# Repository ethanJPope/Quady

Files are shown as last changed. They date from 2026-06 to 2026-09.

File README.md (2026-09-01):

# Quady

Quady is my 8-servo 3D-printed quadruped robot dog project. The goal is to build a real walking robot from scratch, then eventually connect the physical design to simulation and AI training with NVIDIA Isaac Sim / Isaac Lab. This project mixes the parts of engineering I enjoy most: CAD, 3D printing, electronics, programming, and robotics. It is still a work in progress, but the main goal is to get a first version walking and learn enough from it to make the next version better.

## Project Goals

- Build a compact 8-servo quadruped robot dog.
- Design and print the body and legs myself.
- Control the servos through serial bus servo hardware.
- Develop basic movement tests before trying more advanced walking.
- Use simulation and AI training later once the physical design is far enough along.
- Document the process honestly, including the mistakes and redesigns.

## Current Design

Quady is currently an 8-servo robot dog, which means each leg has two powered joints. This keeps the first version simpler than a 12-servo design while still being complex enough to learn real quadruped mechanics and control.

PXL_20260830_213550859 MP

The current plan is:

- 4 legs
- 2 servos per leg
- 8 total servos
- 3D-printed frame and leg parts
- Serial bus servo control
- Future simulation/training work in Isaac Sim and Isaac Lab

## Hardware

Known hardware for the current version:

| Part | Notes |
|---|---|
| Feetech STS3215 servos | 12V serial bus servos |
| Waveshare Bus Servo Adapter | Used to interface with the servos |
| 3D-printed frame and legs | Designed and iterated through CAD |
| External power | Needed for reliable servo testing |

This section will get more specific as the electronics and final mechanical layout become locked in.

In depth assembly instructions can be found here. [ASSEMBLY.md](ASSEMBLY.md).

## Software

The software side is being built in stages:

1. Basic servo communication.
2. Individual joint testing.
3. Leg movement tests.
4. Full-body pose control.
5. Simple walking patterns.
6. Simulation and AI training experiments.

The early focus is on making the real robot move reliably before making the software too complicated.

## Roadmap

- [ ] Finish first complete CAD version.
- [ ] Print and assemble the first full robot body.
- [ ] Test each servo and joint individually.
- [ ] Create basic standing poses.
- [ ] Add simple movement patterns.
- [ ] Record a first walking demo.
- [ ] Start Isaac Sim / Isaac Lab setup.
- [ ] Experiment with AI training once the mechanical design is usable.

## Why I Am Building This

I wanted a project that combines hardware and programming in a way that actually feels challenging. A robot dog is a good target because it forces me to deal with mechanical design, electronics, control systems, and eventually simulation.

This is also a project I want to be able to show as real engineering work, not just a quick demo. The first version does not need to be perfect, but it needs to teach me enough to keep improving it.

## Status

Quady is under active development. The design has changed from a 12-servo robot dog to an 8-servo robot dog to make the first version more realistic and easier to finish.

More build notes, photos, CAD exports, wiring details, and control code will be added as the project develops.

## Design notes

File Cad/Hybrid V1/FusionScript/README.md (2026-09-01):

# Quady Hybrid V1 Fusion script

`QuadyHybridSkeleton.py` creates a new Fusion 360 design for the first hybrid
base-layout check. It does not open or modify the existing Quady V1/V2 CAD.

## What it creates

- Two 260 x 190 mm structural board bodies.
- A 50 mm plane-to-plane board layout offset (46.8 mm clear space between
  3.2 mm board solids).
- Four leg-pivot markers at the current 150 x 100 mm spacing.
- Two 139 x 47 x 40 mm battery keepouts.
- Two Waveshare adapter keepout zones.
- A 75 x 40 mm ESP32-S3 DevKitC-style placeholder envelope around the
  62.74 x 25.40 mm board footprint.
- An optional Raspberry Pi 3B zone.
- An adjustable Arducam camera zone.
- Named millimeter user parameters in Fusion. These drive the initial
  generation; post-run edits are not yet fully associative.

## Run it in Fusion 360

1. Open Fusion 360.
2. Open **Utilities > Add-Ins > Scripts and Add-Ins**.
3. Choose the **Scripts** tab.
4. Click the **+** button and choose **Script or add-in from device**.
5. Select this folder:

   `D:\Quady\Cad\Hybrid V1\FusionScript`

6. Select `QuadyHybridSkeleton.py` and click **Run**.
7. Confirm the new document contains the four named Browser components and
   visible board, battery, electronics, and pivot-marker geometry.

The output is a layout skeleton. Do not use it as a manufacturing file yet. We
will next add the real leg-cassette mounting interface and inspect the physical
clearances. Fusion's Personal plan may show a document-limit read-only banner;
the script remains the reproducible source until the generated document can be
saved.

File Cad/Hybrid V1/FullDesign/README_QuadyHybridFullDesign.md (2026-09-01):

# Quady Hybrid V2 full design

Generated by `QuadyHybridFullDesign.py`.

## Fusion Browser map

| Section | What it contains | Physical treatment |
|---|---|---|
| `10_NONPRINTED_STRUCTURE_FR4_TWO_LAYER` | two 260 x 190 x 3.2 mm boards and four 50 mm spacers | buy/cut: 1.6 mm FR-4 per layer; 6061 aluminum spacers |
| `20_PRINTED_INTERCHANGEABLE_LEG_PARTS` | four leg modules, each with a hip cassette, upper link, and knee cradle | print: PETG-CF or PA12 nylon |
| `30_NONPRINTED_STS3215_SERVOS_12V` | eight positioned servo envelope proxies at the hip/knee shaft datums | buy: STS-3215 12 V servos |
| `40_NONPRINTED_POWER_CONTROL_CAMERA` | two exact battery envelopes, two adapter boards, ESP32-S3, small LiPo, optional Pi 3B, camera, and camera base plate | buy: LiPo/PCBs/camera; print only the retainers/base plate |
| `50_NONPRINTED_FASTENERS_AND_MOUNTING` | M4 cassette/perimeter bolt proxies | buy: stainless M4/M3 hardware |
| `60_REFERENCE_PRESERVED_LOWER_LEG_AND_FOOT` | hidden envelope references for the existing foot/lower leg | keep the existing physical part; do not print these boxes |
| `70_REFERENCE_GROUND_AND_DATUMS` | ground plane and contact datums | construction/reference geometry |
| `80_REFERENCE_STS3215_STEP_SOURCE` | the supplied `D:\Quady\ST3215.step` imported at source origin | reference only until shaft alignment is checked |

## Confirmed design inputs

- Four hip centers use the existing 150 x 100 mm spacing.
- Eight STS-3215 12 V servos are represented: hip and knee on each leg.
- Two batteries are each 139 x 47 x 40 mm.
- Each battery has its own four-servo Waveshare adapter reservation.
- The preferred controller is the supplied ESP32-S3 board; the Pi 3B is only an underside reservation.
- The ground datum is intentionally below the preserved foot envelope, with the target pose encoded from the current 53.882 mm X/Z hip-to-knee vector.

## Print guidance

- Use PETG-CF or PA12 nylon for the structural printed parts.
- Use at least four perimeter walls and 35-45% gyroid infill.
- Print the flat cassette plate and upper link in their shown flat orientations where practical.
- Keep at least 5 mm of solid material around cassette holes; use washers under the board.
- Do not use the battery or servo proxy bodies as print geometry.

## Required measurement gate before final manufacturing CAD

The model is mechanically organized and validated, but these interfaces remain explicitly provisional:

1. STS-3215 outer envelope, shaft center, and mounting-ear pattern.
2. Waveshare adapter outline, hole pattern, connector keepouts, and wire exits.
3. OVO Arducam camera outline and bracket/bolt pattern.
4. Existing foot/lower-leg connection and its real pivot hardware.
5. Actual board material thickness if a different stock thickness is purchased.

Replace the relevant master values in the generator, rerun it, then print one hip cassette and one knee cradle as fit-checks before printing all four legs.

The generated validation record is in `QuadyHybridFullDesign_manifest.json`.

## Alignment feedback loop

The `65_REFERENCE_ALIGNMENT_AUDIT` section is intentionally visible. Use it
as a review gate after every geometry change:

1. Fit the whole assembly in isometric view and confirm all four printed upper links and all eight servo proxies are present.
2. Switch to top view and confirm the four hip axes form the 150 x 100 mm rectangle and each cassette is centered on its axis.
3. Switch to front view and confirm each hip axis, servo shaft, upper-link boss, knee axis, and knee servo shaft are coaxial.
4. Switch to side view and confirm each thin hip-to-knee centerline terminates on both axis datums.
5. Confirm each visible preserved-foot envelope begins at its knee axis; hide the audit group only after this visual check.
6. If any view fails, change the master transform/pose, rerun the generator, and repeat the checks before printing.

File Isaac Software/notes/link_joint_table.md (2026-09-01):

# Quady Link And Joint Table

This file is the planning map for turning Quady from CAD into a robot articulation for URDF, USD, Isaac Sim, and Isaac Lab.

Rule: one link name should represent one rigid physical thing that moves as a single piece.

Current Quady design note: Ethan is using 2 servos per leg, 8 servos total. Earlier 12-DOF assumptions should not be used unless the CAD changes again.

Current CAD organization note: the Fusion assembly is not organized with CAD joints yet. The URDF joint axes are being inferred from the physical servo shaft directions and visual CAD screenshots.

## Link Inventory

- base_body

### Front Left Leg

- front_left_upper_leg
- front_left_lower_leg

### Front Right Leg

- front_right_upper_leg
- front_right_lower_leg

### Rear Left Leg

- rear_left_upper_leg
- rear_left_lower_leg

### Rear Right Leg

- rear_right_upper_leg
- rear_right_lower_leg

## Joint Table

Use this table to record the real CAD joint layout before writing the URDF.

Axis should use the robot coordinate frame:

- `1 0 0` = rotates around X
- `0 1 0` = rotates around Y
- `0 0 1` = rotates around Z

Recommended robot frame:

- X = forward
- Y = left
- Z = up

Axis conclusion for the current 8-servo design:

- Each hip and knee is a pitch joint.
- If the robot frame above is used, the pitch axis is `0 1 0` because the servo shaft points left-right across the robot.
- This was visually checked against side, top, and perspective CAD screenshots on 2026-06-15.

Origin measurement note:

- `fusion_geometry_dump.json` was generated from the open Fusion design on 2026-06-15.
- Fusion API geometry values are in centimeters; table values below are converted to meters.
- The origins below are assembly-frame coordinates from the current Fusion model.
- Current naming assumes the higher-X leg pair is the front pair and positive Y is the left side. Flip front/rear names if Fusion's forward direction is later defined the other way.

| Joint name | Parent link | Child link | Joint type | Axis | Origin xyz, meters | Origin notes | Limits |
|---|---|---|---|---|---|---|---|
| front_left_hip_pitch | base_body | front_left_upper_leg | revolute | `0 1 0` | `-0.025500 0.090975 0.000000` | inferred from upper-leg hip pivot cylinder | TBD |
| front_left_knee_pitch | front_left_upper_leg | front_left_lower_leg | revolute | `0 1 0` | `0.028382 0.090975 -0.053882` | inferred from matching upper/lower-leg knee pivot cylinders | TBD |
| front_right_hip_pitch | base_body | front_right_upper_leg | revolute | `0 1 0` | `-0.025500 -0.009025 0.000000` | inferred from upper-leg hip pivot cylinder | TBD |
| front_right_knee_pitch | front_right_upper_leg | front_right_lower_leg | revolute | `0 1 0` | `0.028382 -0.009025 -0.053882` | inferred from matching upper/lower-leg knee pivot cylinders | TBD |
| rear_left_hip_pitch | base_body | rear_left_upper_leg | revolute | `0 1 0` | `-0.175500 0.090975 0.000000` | inferred from upper-leg hip pivot cylinder | TBD |
| rear_left_knee_pitch | rear_left_upper_leg | rear_left_lower_leg | revolute | `0 1 0` | `-0.121618 0.090975 -0.053882` | inferred from matching upper/lower-leg knee pivot cylinders | TBD |
| rear_right_hip_pitch | base_body | rear_right_upper_leg | revolute | `0 1 0` | `-0.175500 -0.009025 0.000000` | inferred from upper-leg hip pivot cylinder | TBD |
| rear_right_knee_pitch | rear_right_upper_leg | rear_right_lower_leg | revolute | `0 1 0` | `-0.121618 -0.009025 -0.053882` | inferred from matching upper/lower-leg knee pivot cylinders | TBD |

## Mesh Export Checklist

Each final link should get a visual mesh. Collision meshes started as matching STL files, but the active URDF now uses simple primitive box collisions because the full visual STL collisions made Isaac Sim contact behavior look weird.

| Link | Visual mesh | Collision mesh | Exported? | Notes |
|---|---|---|---|---|
| base_body | meshes/visual/base_body.stl | meshes/collision/base_body.stl | yes | Exported from Fusion root body `Body` |
| front_left_upper_leg | meshes/visual/front_left_upper_leg.stl | meshes/collision/front_left_upper_leg.stl | yes | Exported from Fusion root body `Upper Leg (1)` |
| front_left_lower_leg | meshes/visual/front_left_lower_leg.stl | meshes/collision/front_left_lower_leg.stl | yes | Exported from Fusion root body `Lower Leg (1)` |
| front_right_upper_leg | meshes/visual/front_right_upper_leg.stl | meshes/collision/front_right_upper_leg.stl | yes | Exported from Fusion root body `Upper Leg` |
| front_right_lower_leg | meshes/visual/front_right_lower_leg.stl | meshes/collision/front_right_lower_leg.stl | yes | Exported from Fusion root body `Lower Leg` |
| rear_left_upper_leg | meshes/visual/rear_left_upper_leg.stl | meshes/collision/rear_left_upper_leg.stl | yes | Exported from Fusion root body `Upper Leg (1) (1) (1)` |
| rear_left_lower_leg | meshes/visual/rear_left_lower_leg.stl | meshes/collision/rear_left_lower_leg.stl | yes | Exported from Fusion root body `Lower Leg (1) (1) (1)` |
| rear_right_upper_leg | meshes/visual/rear_right_upper_leg.stl | meshes/collision/rear_right_upper_leg.stl | yes | Exported from Fusion root body `Upper Leg (1) (1)` |
| rear_right_lower_leg | meshes/visual/rear_right_lower_leg.stl | meshes/collision/rear_right_lower_leg.stl | yes | Exported from Fusion root body `Lower Leg (1) (1)` |

## URDF Status

- Initial URDF created at `urdf/quady.urdf`.
- XML validation passed on 2026-06-15.
- Mesh path check passed on the first mesh-based URDF: 18 mesh references, 0 missing files.
- Collision validation after the first Isaac Sim physics test: 9 primitive collision boxes, 0 collision mesh references.
- Primitive collision boxes are intentionally smaller than the visual meshes so the solver does not use detailed CAD surfaces as contact geometry.
- Current test hip limits are `0.0000` to `0.7854` rad, effort `3.0`, velocity `5.0`.
- Current test knee limits are `-1.5708` to `0.6981` rad, effort `3.0`, velocity `5.0`.
- These limits were set after Isaac Sim showed upper-leg geometry rotating through the base body with the earlier +/-90 and +/-60 degree placeholders.
- Inertial values are rough placeholders and should be tuned before serious simulation/training.

## USD Status

- URDF converted successfully with Isaac Lab on 2026-06-15.
- Main USD asset: `usd/quady/quady.usda`.
- Converter output includes PhysX and MuJoCo physics payloads.
- Generated USD inspection found 8 `PhysicsRevoluteJoint` entries with `physics:axis = "Y"`.
- First visual inspection in Isaac Sim: asset is visible and no warning text appeared on Play. It fell under gravity.
- Ethan's screen recording showed the legs stayed attached and rotated around the correct joints, but collision/contact looked weird. The likely cause was using full visual STL copies as collision meshes.
- The URDF was updated to use primitive box collisions and reconverted. The updated viewer stage now references `usd/quady_2/quady.usda`.
- `usd/quady_2/quady.usda` has position drives enabled from the URDF converter, using converter inputs `--joint-stiffness 20.0 --joint-damping 2.0 --joint-target-type position`. This makes joints act springy and snap back toward their target pose.
- `usd/quady_3/quady.usda` is the passive limited test asset, generated with `--joint-stiffness 0.0 --joint-damping 0.0 --joint-target-type none`. Use this for collision/range testing when manual dragging should not spring back.
- `usd/quady_4/quady.usda` is the current passive test asset with all 8 joints limited to 0 to +45 degrees.
- `usd/quady_5/quady.usda` is the current passive split-limit asset: hips 0 to +45 degrees, knees -90 to +40 degrees.
- `usd/quady_neutral_passive/quady.usda` is a copied passive split-limit asset with initial joint state positions set to hips +20 degrees and knees -45 degrees. Open it through `usd/quady_view_stage_neutral.usda`.
- Visible servo housings are not included in this first pass because only root body/leg bodies were exported into the URDF. Add visual-only ST3215 meshes later if needed.
- Troubleshooting note: `usd/quady/quady.usda` was once overwritten by Isaac Sim as an empty scene with `/World` and `/Environment`, which made frame-selection show nothing. It was restored and the empty overwritten file was backed up as `usd/quady/quady.empty-scene-backup.usda`.
- Safer visual-inspection stage: open `usd/quady_view_stage.usda`, which references the robot asset under `/World/Quady`.

## Open Questions

- Are the exported STL files in millimeters? If yes, the URDF mesh scale should probably be `0.001 0.001 0.001`.
- What are the real safe joint limits for the STS3215 servos in this mechanical design?
- Which direction is forward in the Fusion assembly?
- Confirm whether the higher-X leg pair should be named front or rear.
- Decide whether the URDF will use assembly-frame mesh coordinates or link-local mesh coordinates. This affects whether the table's assembly-frame origins can be used directly.

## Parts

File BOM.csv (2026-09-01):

Line | Category | Product | Brand / Manufacturer | Model / Part Number | Supplier | Supplier Part ID | Order Quantity | Units per Order | Total Physical Units | Unit Type | Product Link | Notes | Verified On
1 | Power - Charger | B3 LiPo balance charger, 2S/3S, 7.4-11.1V, 10W, XH-3P/XH-4P | Tosiicop | B3 | Amazon | B0FDKX4V38 | 1 | 1 | 1 | charger | https://www.amazon.com/dp/B0FDKX4V38 | One charger per listing; listing states 0.8A output. | 2026-08-31
2 | Power - Battery | 3S LiPo battery, 11.1V, 5200mAh, 80C, hard case, XT60 (2-pack) | Hilldow | CM5202 | Amazon | B0FW4RJXT3 | 2 | 2 | 4 | battery | https://www.amazon.com/dp/B0FW4RJXT3 | Two batteries per listing; ordering two listings gives four batteries. | 2026-08-31
3 | Electrical - Connector | XT60H / XT-60 male and female bullet connector pair (5-pair pack) | Ledvillage | 5-XT60-SH-M/F | Amazon | B0DB1V6FFY | 1 | 5 | 5 | connector pair | https://www.amazon.com/dp/B0DB1V6FFY | Five male/female connector pairs per listing. | 2026-08-31
4 | Electronics - Servo Interface | Bus Servo Adapter (A) serial bus servo driver board (2-pack) | Waveshare | 2PCS Bus Servo Adapter (A) | Amazon | B0DK79JNNK | 1 | 2 | 2 | adapter board | https://www.amazon.com/dp/B0DK79JNNK | Two Waveshare Bus Servo Adapter (A) boards per listing. | 2026-08-31
5 | Actuator - Servo | STS3215 12V 30kg magnetic-encoder TTL serial bus servo | DIYmall | STS3215 | Amazon | B0FGNTDV3Y | 8 | 1 | 8 | servo | https://www.amazon.com/dp/B0FGNTDV3Y | 12V version; one servo per listing. | 2026-08-31
6 | Electronics - Controller | ESP32-S3-DevKitC-1U-N8R8 development board | Espressif Systems | ESP32-S3-DEVKITC-1U-N8R8 | DigiKey | 1965-ESP32-S3-DEVKITC-1U-N8R8-ND | 1 | 1 | 1 | development board | https://www.digikey.com/en/products/detail/espressif-systems/ESP32-S3-DEVKITC-1U-N8R8/16162636 | Linked board uses the ESP32-S3-WROOM-1U-N8R8 module (external-antenna version), not the WROOM-1 PCB-antenna version. | 2026-08-31

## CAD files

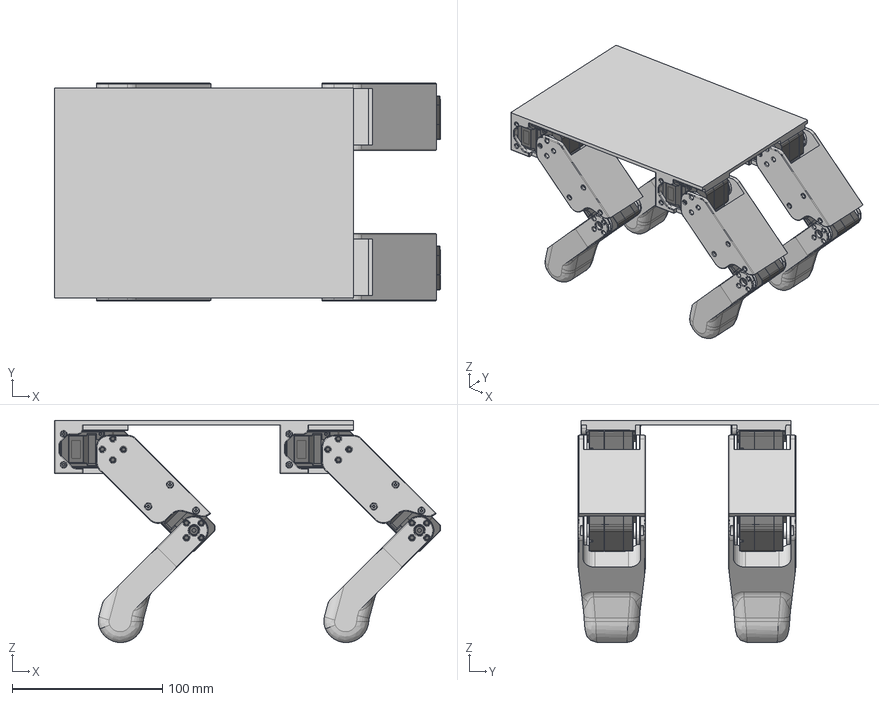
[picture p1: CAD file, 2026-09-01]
Cad/V2/Quady Assembly.step
256.7 x 144.9 x 147.7 mm
Chassis_Top
Chassis_Bottom
Test
ZK_122 x 8
SG-ZIJI_15 x 8
XG-ZIJI_16 x 8
MOTOR-1723_3 x 8
PCB-CHAZUO_92 x 8
GE_27 x 8
金属舵盘（驱动） x 8
金属舵盘（从动） x 8
Test2

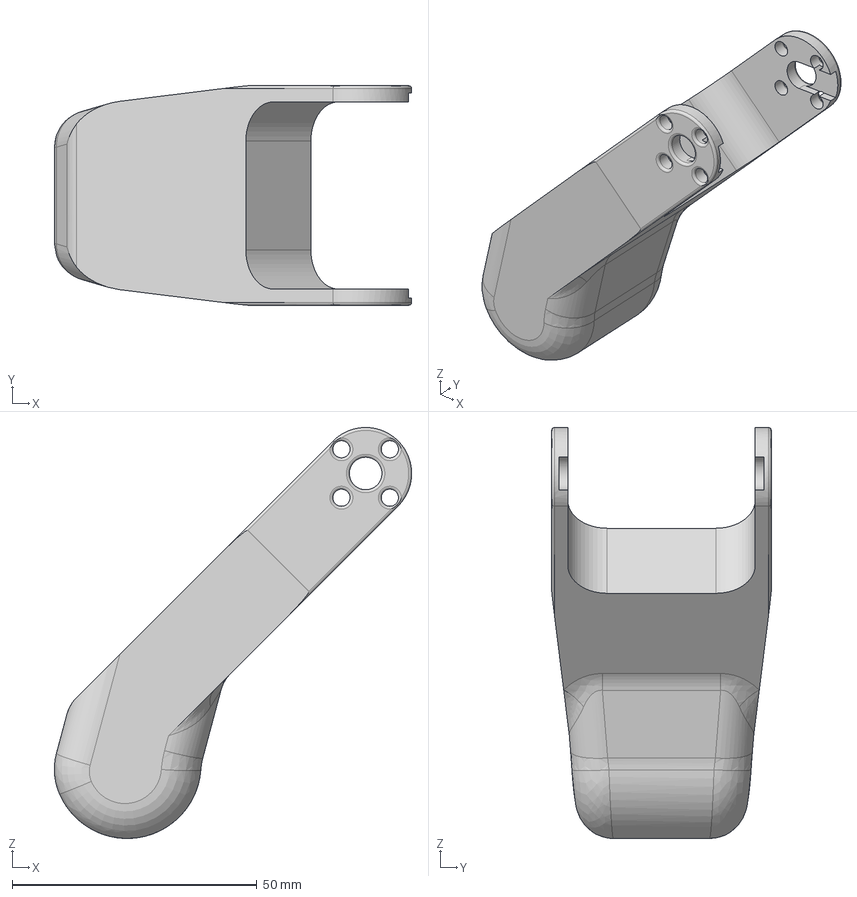
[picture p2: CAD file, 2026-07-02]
Cad/Current Verion(step files)/Lower Leg.step
73.0 x 44.9 x 84.0 mm

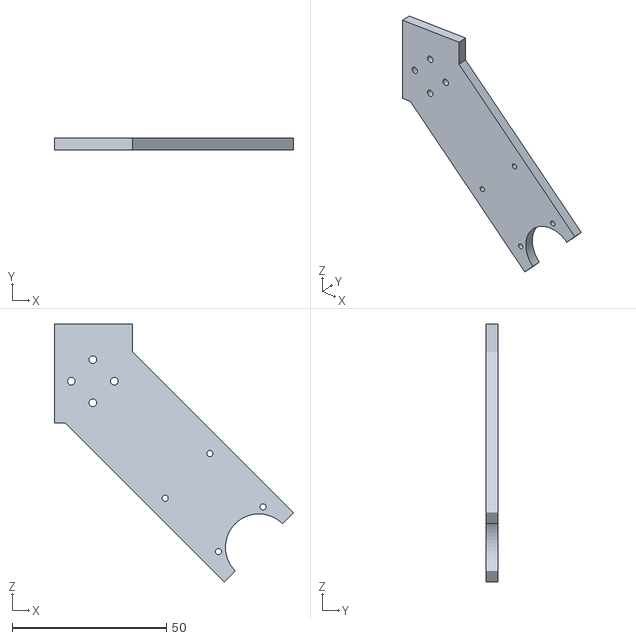
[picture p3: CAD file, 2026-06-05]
Cad/Initial Testing/Test Measurments Part.stl
77.6 x 3.81 x 83.7

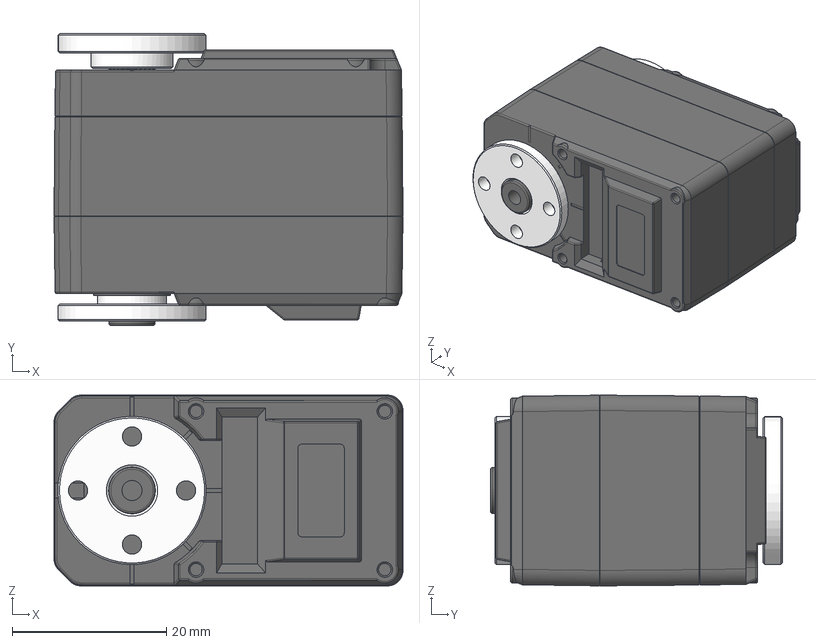
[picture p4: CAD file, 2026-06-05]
ST3215.step
45.2 x 37.8 x 24.7 mm
ZK_122
SG-ZIJI_15
XG-ZIJI_16
MOTOR-1723_3
PCB-CHAZUO_92
GE_27
金属舵盘（驱动）
金属舵盘（从动）

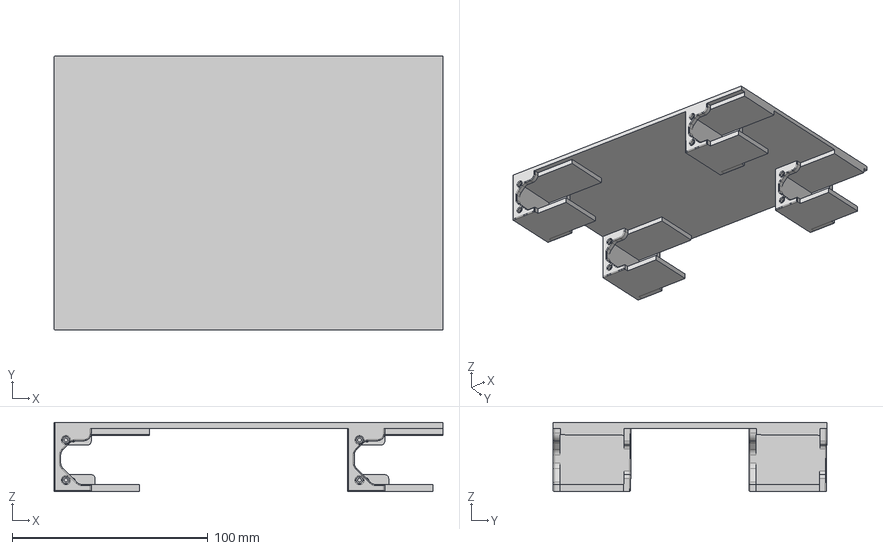
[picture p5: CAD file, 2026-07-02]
Cad/Current Verion(step files)/Body.step
198.8 x 139.9 x 35.3 mm

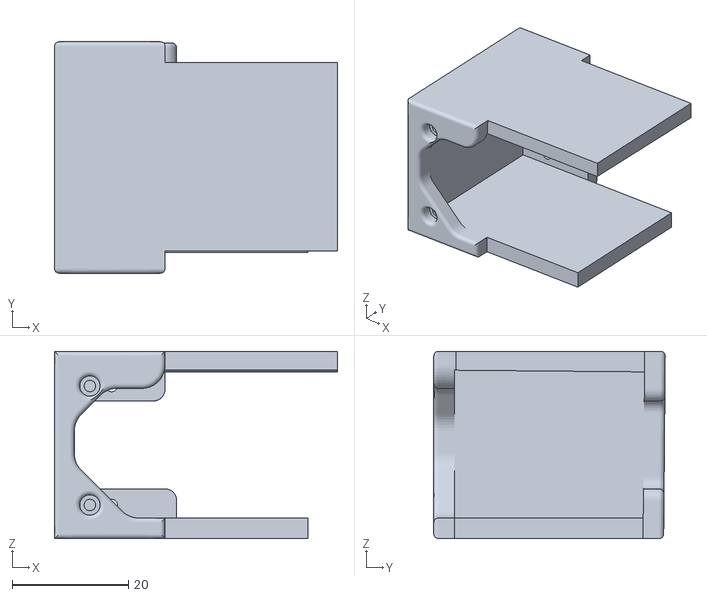
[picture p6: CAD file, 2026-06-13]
Cad/V2/ServoClip.stl
48.8 x 39.9 x 32.3

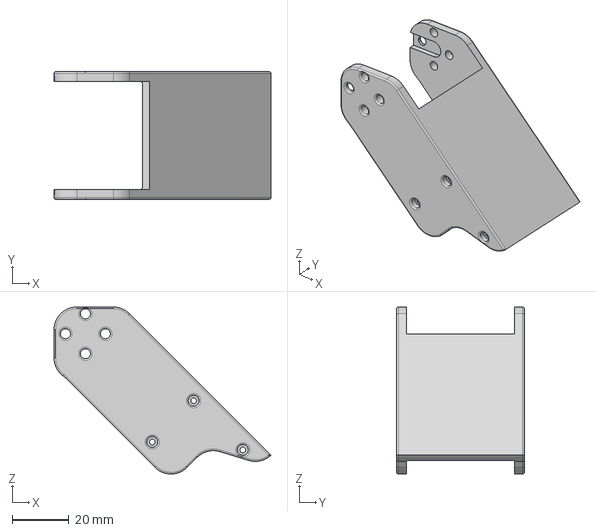
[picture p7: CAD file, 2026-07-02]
Cad/Current Verion(step files)/Upper Leg.step
76.2 x 44.9 x 58.6 mm

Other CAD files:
Isaac Software/meshes/collision/rear_left_lower_leg.stl
Isaac Software/meshes/visual/rear_left_lower_leg.stl
Isaac Software/meshes/collision/rear_right_lower_leg.stl
Isaac Software/meshes/visual/base_body.stl
Cad/V2/Body.stl
Isaac Software/meshes/collision/front_left_upper_leg.stl
Isaac Software/meshes/visual/front_left_upper_leg.stl
Cad/V2/Upper Leg.stl
Isaac Software/meshes/collision/front_left_lower_leg.stl
Isaac Software/meshes/visual/front_right_upper_leg.stl
Cad/V2/Lower Leg.stl
Cad/V1/Lower Leg.stl
Cad/V1/Quady Assembly V1.f3z
Cad/V1/Upper Leg.stl
Cad/V2/Quady Assembly.f3z
Isaac Software/meshes/collision/base_body.stl
Isaac Software/meshes/collision/front_right_lower_leg.stl
Isaac Software/meshes/collision/front_right_upper_leg.stl
Isaac Software/meshes/collision/rear_left_upper_leg.stl
Isaac Software/meshes/collision/rear_right_upper_leg.stl
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

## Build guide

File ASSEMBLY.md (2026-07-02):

# Quady Quick Assembly Notes

These are current first-version assembly notes for Quady. They are meant to get the physical robot assembled and wired far enough for safe servo ID checks, range checks, and early movement tests.

## Current Version

- 8-servo quadruped
- 2 powered joints per leg
- Feetech STS3215 12 V serial bus servos
- 2x Waveshare Bus Servo Adapter boards
- ESP32 / ESP32-S3 controller
- 3D-printed body, lower legs, upper legs, and servo clips

CAD files for the current printed version are in `Cad/V2/`.

## Parts To Print

Print these from `Cad/V2/`:

- `Body.stl`
- `Upper Leg.stl` x4
- `Lower Leg.stl` x4
- `ServoClip.stl` as needed for retaining the servos

Use the STEP assembly in `Cad/V2/Quady Assembly.step` as the visual reference while assembling.

## Before Mechanical Assembly

1. Label the servos before installing them.
2. Give each servo a unique ID from `1` to `8`.
3. Keep IDs `1-4` on bus 1 and IDs `5-8` on bus 2.
4. Test each servo by itself before putting it into the body.
5. Do not force a servo horn through the printed joint travel. If it binds, stop and fix the print, alignment, or range.

The important idea: make every servo known-good before it becomes hard to reach.

## Suggested Servo Layout

Use this as the starting ID map unless you decide to change the gait code later:

| Servo ID | Bus | Suggested joint |
|---|---:|---|
| 1 | 1 | front left hip/shoulder |
| 2 | 1 | front left knee |
| 3 | 1 | rear left hip/shoulder |
| 4 | 1 | rear left knee |
| 5 | 2 | front right hip/shoulder |
| 6 | 2 | front right knee |
| 7 | 2 | rear right hip/shoulder |
| 8 | 2 | rear right knee |

If the physical layout makes a different map cleaner, update this table and the code together.

## Mechanical Assembly

1. Install the servos into the body.
2. Add servo clips or retainers so the servos cannot slide out under load.
3. Attach each upper leg to its hip/shoulder servo.
4. Attach each lower leg to its knee servo.
5. Move each leg by hand through its expected range before powering anything.
6. Check that wires can move without getting pulled, pinched, or wrapped around a joint.
7. Keep the robot supported while testing. Do not let the full weight sit on an uncalibrated pose yet.

## Wiring Overview

Quady uses serial bus servos, so the Waveshare boards are acting as the servo bus interface between the ESP32 and the STS3215 servos.

Each bus needs:

- ESP32 TX to adapter RX
- ESP32 RX to adapter TX
- ESP32 GND to adapter GND
- External servo power connected to the servo power input
- Servos daisy-chained on the matching bus

The servo power supply must be separate from the ESP32 USB power. The grounds must still be connected.

## Current Two-Bus ESP32 Wiring

The current multi-bus sketches, including `ServoTester/ServoTester.ino` and `ID_Checker/ID_Checker.ino`, use this pinout:

| Bus | ESP32 TX | ESP32 RX | Servo IDs |
|---|---:|---:|---|
| Bus 1 | GPIO 9 | GPIO 10 | 1-4 |
| Bus 2 | GPIO 11 | GPIO 12 | 5-8 |

Wire each Waveshare adapter like this:

| ESP32 | Waveshare bus servo adapter |
|---|---|
| GPIO 9 | Bus 1 RX |
| GPIO 10 | Bus 1 TX |
| GPIO 11 | Bus 2 RX |
| GPIO 12 | Bus 2 TX |
| GND | GND on both adapters |

Then connect servos `1-4` to the first adapter and servos `5-8` to the second adapter.

## Older Utility Sketch Pinouts

Some older single-bus test sketches use different pins:

| Sketch | TX | RX |
|---|---:|---:|
| `One_Servo_Test/One_Servo_Test.ino` | GPIO 17 | GPIO 18 |
| `ID_Editor/ID_Editor.ino` | GPIO 17 | GPIO 18 |

`ServoID_Recovery/ServoID_Recovery.ino` uses:

| Bus | TX | RX |
|---|---:|---:|
| Bus 1 | GPIO 17 | GPIO 18 |
| Bus 2 | GPIO 15 | GPIO 16 |

Before uploading a sketch, check the pin definitions at the top of the file and make sure the wiring matches that sketch.

## Power Safety

1. Use a 12 V supply that can handle servo current.
2. Power the ESP32 from USB or its normal logic input.
3. Power the STS3215 servos from the servo power input on the adapter.
4. Connect grounds together between the ESP32, both adapters, and the servo power supply.
5. Do not power the servos only from the ESP32.
6. During first tests, keep one hand near the power switch or unplug point.

If a servo gets hot, chatters, or drives into a hard stop, kill power and fix the range before continuing.

## Bring-Up Order

1. Upload `One_Servo_Test/One_Servo_Test.ino` and verify one loose servo moves safely.
2. Use `ID_Editor/ID_Editor.ino` or `ServoID_Recovery/ServoID_Recovery.ino` to assign unique IDs.
3. Upload `ID_Checker/ID_Checker.ino` and confirm all IDs respond on the expected bus.
4. Upload `ServoTester/ServoTester.ino`.
5. Use the serial monitor at `115200` baud.
6. Type `help` to see commands.
7. Use `list` to check saved ranges.
8. Use `nudge <id> <ticks>` for tiny movements.
9. Use `mark <id> a` and `mark <id> b` to save safe endpoints.
10. Use `test <id>` only after a servo has a known safe range.

Start with the robot lifted off the table so a wrong direction cannot make the leg jam into the ground.

## First Full-Body Test

1. Confirm every servo ID responds.
2. Confirm every joint has a saved safe range.
3. Move each servo to roughly center position.
4. Install the legs in a neutral stance.
5. Run one joint at a time with a small buffer.
6. Watch for mirrored legs moving opposite directions.
7. Fix the ID map, horn orientation, or range before trying full poses.

The first goal is not walking. The first goal is reliable, boring, repeatable joint control.

## Current Open Items

- Finalize the real servo ID to leg/joint map.
- Decide whether the current default ESP32 pins should stay `9/10` and `11/12`, or whether all utility sketches should be standardized around another pinout.
- Add photos of the assembled wiring once the layout is locked in.
- Add a final standing pose procedure after joint ranges are calibrated.

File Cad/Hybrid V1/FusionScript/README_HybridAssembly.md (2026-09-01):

# Quady Hybrid V1 — complete Fusion assembly generator

File: `QuadyHybridAssembly.py`

This generator creates a new Fusion design and leaves the existing V1/V2
files untouched. It is the single layout/reference master for the proposed
hybrid build. It is not yet the final printable part set: the foot mating
geometry, servo bracket pattern, adapter pattern, and camera bracket still
need measured interfaces.

- two 260 × 190 × 3.2 mm structural boards;
- 50 mm clear space between the board faces;
- four interchangeable leg-cassette pads at the confirmed 150 × 100 mm hip
  spacing;
- two editable battery clearance bays plus hidden 139 × 47 × 40 mm pack
  reference solids;
- two separate four-servo Waveshare adapter envelopes;
- ESP32-S3 and small ESP32 LiPo reservations;
- optional Raspberry Pi 3B reservation on the underside of the lower board;
- OVO Arducam camera reservation and printed bracket plate;
- hardware/standoff references;
- ground-clearance reference at 70 mm;
- labeled preserved-foot STL bounding-box and STS-3215 reference geometry;
- an in-Fusion validation report.

## Run it

1. Open Fusion 360.
2. Open **Utilities → Add-Ins → Scripts and Add-Ins**.
3. Import this folder as a Fusion script if it is not already listed.
4. Select `QuadyHybridAssembly` and click **Run**.
5. In the generated document, expand the numbered components in the Browser.
6. Open **Modify → Change Parameters** to change the named dimensions.
7. Rerun the generator after changing a design assumption. It always creates a
   fresh document so the prior generated result remains available for review.
   Fusion Personal may limit how many unsaved documents can be open, so close
   an old test document before repeated runs if Fusion reports a document-limit
   warning.

## What is exact versus provisional

Confirmed inputs currently encoded:

- battery outer dimensions: 139 × 47 × 40 mm;
- four legs, two STS-3215 servos per leg;
- two battery-to-adapter power groups;
- hip pivot spacing: 150 × 100 mm;
- nominal ESP32-S3 PCB envelope: 62.74 × 25.40 mm.

Provisional values are intentionally named in the Browser and in the script:

- cassette hole pitch and printed cassette thickness;
- STS-3215 bracket/servo mounting pattern;
- Waveshare adapter board mounting pattern;
- OVO Arducam camera bracket and lens keepout;
- small ESP32 LiPo outer dimensions;
- actual board stock/material and final fastener sizes.

The printed `PRESERVED_Lower_Leg_Foot_STL_Bounding_Box_REFERENCE_ONLY` is a
disabled visual bounding box based on the existing STL dimensions. It is not a
printable replacement for the existing foot and does not prove the mating
interface. Measure the real foot and cassette interface before making final
printed parts.

The battery bays and Waveshare/ESP32/Pi zones are clearance geometry. Hidden
reference solids show the nominal board or pack dimensions. The cassette
mount cylinders are additive clearance-reference solids, not subtractive
holes; the final cassette must be cut from the board using the measured hole
pattern.

The optional Pi reservation is intentionally on the underside of the lower
board, so it can occupy the same plan-view footprint as upper-board camera
hardware without being treated as a same-layer collision.

## Material starting point

The generator intentionally does not bake in a purchase decision. The two
board layers are represented as solids with editable thickness. Start with
3.2 mm FR-4, birch plywood, or another stiff sheet that can be drilled cleanly;
choose only after checking the final mass, fastener pull-through, and access
to both faces. The design's board thickness parameter makes that comparison
easy without rewriting the layout.

## Safety and review gates before printing

1. Measure the actual Waveshare adapter outline and hole pattern.
2. Measure one STS-3215 body, horn center, bolt pattern, and cable exit.
3. Measure the existing foot's mating faces and preserve those datums.
4. Replace the cassette placeholders with those measurements.
5. Confirm battery retention, connector bend radius, and center of mass.
6. Confirm that the two board layers cannot pinch servo wires or battery leads.
7. Print only a single cassette test coupon before printing all four.

The default battery bay is 45 mm tall inside the 50 mm board gap, leaving a
nominal 5 mm upper-board headroom margin. That is a layout margin, not a
guarantee of connector bend-radius or wire-pinch clearance; verify the actual
battery leads before locking the board spacing.

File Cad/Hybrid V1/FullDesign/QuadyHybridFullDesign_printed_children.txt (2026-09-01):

build_id=HYBRID_V2_DIRECT_CHILD_COMPONENTS_2026-08-08
count=16
0:FL_PRINTED_LEG_MODULE
1:FL_PRINTED_HIP_CASSETTE
2:FL_PRINTED_UPPER_LEG
3:FL_PRINTED_KNEE_CRADLE
4:FR_PRINTED_LEG_MODULE
5:FR_PRINTED_HIP_CASSETTE
6:FR_PRINTED_UPPER_LEG
7:FR_PRINTED_KNEE_CRADLE
8:RL_PRINTED_LEG_MODULE
9:RL_PRINTED_HIP_CASSETTE
10:RL_PRINTED_UPPER_LEG
11:RL_PRINTED_KNEE_CRADLE
12:RR_PRINTED_LEG_MODULE
13:RR_PRINTED_HIP_CASSETTE
14:RR_PRINTED_UPPER_LEG
15:RR_PRINTED_KNEE_CRADLE

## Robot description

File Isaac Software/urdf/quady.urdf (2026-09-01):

<?xml version="1.0"?>
<robot name="quady">
  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

  <link name="base_body">
    <inertial>
      <origin xyz="-0.114966 0.040271 0.001584" rpy="0 0 0"/>
      <mass value="0.500"/>
      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
    </inertial>
    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
  </link>

  <link name="front_left_upper_leg">
    <inertial>
      <origin xyz="0.027049 0.000000 -0.019913" rpy="0 0 0"/>
      <mass value="0.080"/>
      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
    </inertial>
    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
  </link>

  <link name="front_left_lower_leg">
    <inertial>
      <origin xyz="-0.027118 0.000000 -0.032596" rpy="0 0 0"/>
      <mass value="0.080"/>
      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
    </inertial>
    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
  </link>

  <link name="front_right_upper_leg">
    <inertial>
      <origin xyz="0.027049 0.000000 -0.019913" rpy="0 0 0"/>
      <mass value="0.080"/>
      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
    </inertial>
    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
  </link>

  <link name="front_right_lower_leg">
    <inertial>
      <origin xyz="-0.027118 0.000000 -0.032596" rpy="0 0 0"/>
      <mass value="0.080"/>
      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
    </inertial>
    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
  </link>

  <link name="rear_left_upper_leg">
    <inertial>
      <origin xyz="0.027049 0.000000 -0.019913" rpy="0 0 0"/>
      <mass value="0.080"/>
      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
    </inertial>
    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
  </link>

  <link name="rear_left_lower_leg">
    <inertial>
      <origin xyz="-0.027118 0.000000 -0.032596" rpy="0 0 0"/>
      <mass value="0.080"/>
      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
    </inertial>
    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
  </link>

  <link name="rear_right_upper_leg">
    <inertial>
      <origin xyz="0.027049 0.000000 -0.019913" rpy="0 0 0"/>
      <mass value="0.080"/>
      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
    </inertial>
    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
  </link>

  <link name="rear_right_lower_leg">
    <inertial>
      <origin xyz="-0.027118 0.000000 -0.032596" rpy="0 0 0"/>
      <mass value="0.080"/>
      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
    </inertial>
    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
  </link>

  <joint name="front_left_hip_pitch" type="revolute">
    <parent link="base_body"/>
    <child link="front_left_upper_leg"/>
    <origin xyz="-0.025500 0.090975 0.000000" rpy="0 0 0"/>
    <axis xyz="0 1 0"/>
    <limit lower="0.0000" upper="0.7854" effort="3.0" velocity="5.0"/>
  </joint>

  <joint name="front_left_knee_pitch" type="revolute">
    <parent link="front_left_upper_leg"/>
    <child link="front_left_lower_leg"/>
    <origin xyz="0.053882 0.000000 -0.053882" rpy="0 0 0"/>
    <axis xyz="0 1 0"/>
    <limit lower="-1.5708" upper="0.6981" effort="3.0" velocity="5.0"/>
  </joint>

  <joint name="front_right_hip_pitch" type="revolute">
    <parent link="base_body"/>
    <child link="front_right_upper_leg"/>
    <origin xyz="-0.025500 -0.009025 0.000000" rpy="0 0 0"/>
    <axis xyz="0 1 0"/>
    <limit lower="0.0000" upper="0.7854" effort="3.0" velocity="5.0"/>
  </joint>

  <joint name="front_right_knee_pitch" type="revolute">
    <parent link="front_right_upper_leg"/>
    <child link="front_right_lower_leg"/>
    <origin xyz="0.053882 0.000000 -0.053882" rpy="0 0 0"/>
    <axis xyz="0 1 0"/>
    <limit lower="-1.5708" upper="0.6981" effort="3.0" velocity="5.0"/>
  </joint>

  <joint name="rear_left_hip_pitch" type="revolute">
    <parent link="base_body"/>
    <child link="rear_left_upper_leg"/>
    <origin xyz="-0.175500 0.090975 0.000000" rpy="0 0 0"/>
    <axis xyz="0 1 0"/>
    <limit lower="0.0000" upper="0.7854" effort="3.0" velocity="5.0"/>
  </joint>

  <joint name="rear_left_knee_pitch" type="revolute">
    <parent link="rear_left_upper_leg"/>
    <child link="rear_left_lower_leg"/>
    <origin xyz="0.053882 0.000000 -0.053882" rpy="0 0 0"/>
    <axis xyz="0 1 0"/>
    <limit lower="-1.5708" upper="0.6981" effort="3.0" velocity="5.0"/>
  </joint>

  <joint name="rear_right_hip_pitch" type="revolute">
    <parent link="base_body"/>
    <child link="rear_right_upper_leg"/>
    <origin xyz="-0.175500 -0.009025 0.000000" rpy="0 0 0"/>
    <axis xyz="0 1 0"/>
    <limit lower="0.0000" upper="0.7854" effort="3.0" velocity="5.0"/>
  </joint>

  <joint name="rear_right_knee_pitch" type="revolute">
    <parent link="rear_right_upper_leg"/>
    <child link="rear_right_lower_leg"/>
    <origin xyz="0.053882 0.000000 -0.053882" rpy="0 0 0"/>
    <axis xyz="0 1 0"/>
    <limit lower="-1.5708" upper="0.6981" effort="3.0" velocity="5.0"/>
  </joint>
</robot>

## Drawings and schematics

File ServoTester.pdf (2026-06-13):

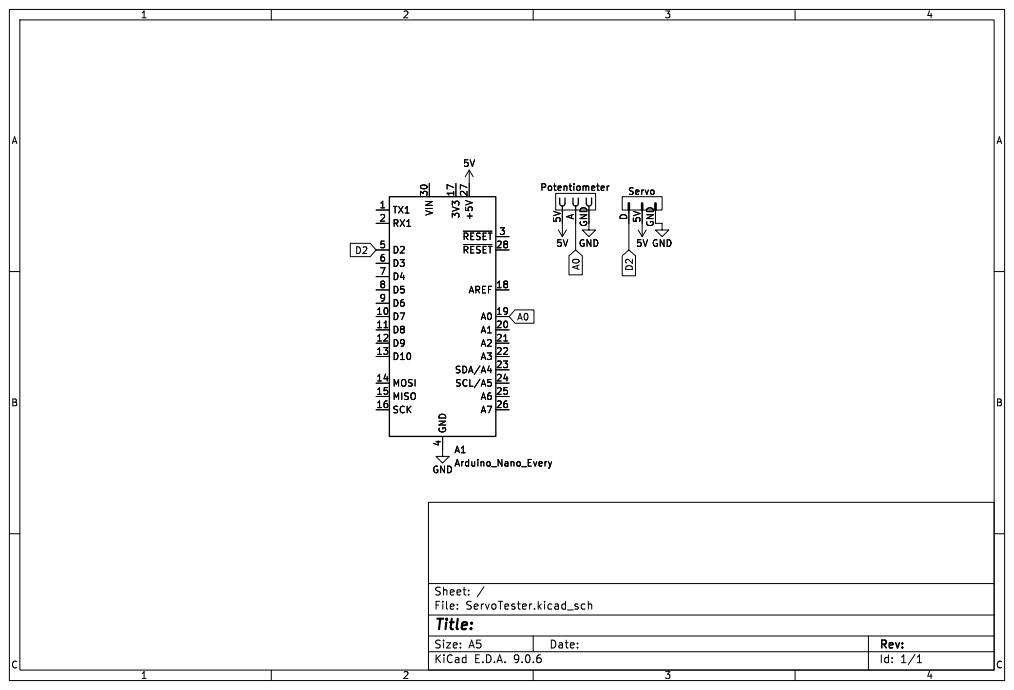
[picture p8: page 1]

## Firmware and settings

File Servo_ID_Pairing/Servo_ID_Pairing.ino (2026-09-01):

#include <SCServo.h>

// Quadi final wiring (ESP32-S3-WROOM-1 -> Waveshare Bus Servo Adapter (A)).
// Waveshare's UART labels connect same-name: ESP32 RX -> adapter RX,
// ESP32 TX -> adapter TX. Put each adapter's jumper in position A.
constexpr uint8_t RIGHT_TX_PIN = 11;
constexpr uint8_t RIGHT_RX_PIN = 12;
constexpr uint8_t LEFT_TX_PIN = 13;
constexpr uint8_t LEFT_RX_PIN = 14;

constexpr uint32_t CONSOLE_BAUD = 115200;
constexpr uint32_t SERVO_BAUD = 1000000;
constexpr unsigned long SERVO_IO_TIMEOUT_MS = 20;

constexpr uint8_t MIN_SERVO_ID = 0;
constexpr uint8_t MAX_SERVO_ID = 253;
constexpr uint8_t DEFAULT_SCAN_MAX_ID = 20;
constexpr size_t MAX_TRACKED_SERVOS = 16;

// About 5.3 degrees on a 4096-tick revolution. Two readings must cross this
// threshold before a servo is selected.
constexpr int MOVE_THRESHOLD_TICKS = 60;
constexpr uint8_t MOVE_CONFIRM_READS = 2;
constexpr unsigned long POLL_INTERVAL_MS = 20;
constexpr unsigned long READ_FAILURE_REPORT_MS = 2000;
constexpr unsigned long POST_WRITE_DELAY_MS = 120;
constexpr unsigned long ISOLATION_CONFIRMATION_WINDOW_MS = 60000;

HardwareSerial rightSerial(1);
HardwareSerial leftSerial(2);
SMS_STS rightDriver;
SMS_STS leftDriver;

struct ServoBus {
  const char *name;
  HardwareSerial *serial;
  SMS_STS *driver;
  uint8_t rxPin;
  uint8_t txPin;
  uint8_t allowedIdMin;
  uint8_t allowedIdMax;
};

ServoBus rightBus = {
  "RIGHT", &rightSerial, &rightDriver,
  RIGHT_RX_PIN, RIGHT_TX_PIN, 1, 4
};

ServoBus leftBus = {
  "LEFT", &leftSerial, &leftDriver,
  LEFT_RX_PIN, LEFT_TX_PIN, 5, 8
};

ServoBus *buses[] = {&rightBus, &leftBus};
constexpr size_t BUS_COUNT = sizeof(buses) / sizeof(buses[0]);

struct TrackedServo {
  ServoBus *bus;
  uint8_t id;
  int baselinePosition;
  int lastPosition;
  uint8_t movementHits;
  bool positionReadable;
  bool torqueDisabled;
};

TrackedServo tracked[MAX_TRACKED_SERVOS];
size_t trackedCount = 0;
size_t pollIndex = 0;
unsigned long lastPollMs = 0;
unsigned long lastReadFailureReportMs = 0;
uint8_t lastScanMaxId = DEFAULT_SCAN_MAX_ID;

enum class PairingState {
  WATCHING,
  AWAITING_TARGET_ID,
  AWAITING_ISOLATION,
  AWAITING_CONFIRMATION
};

PairingState state = PairingState::WATCHING;
TrackedServo *selectedServo = nullptr;
int requestedNewId = -1;
bool isolationVerified = false;
unsigned long isolationVerifiedAtMs = 0;

static bool isValidServoId(int id) {
  return id >= MIN_SERVO_ID && id <= MAX_SERVO_ID;
}

static bool isAllowedTargetForBus(const ServoBus &bus, int id) {
  return id >= bus.allowedIdMin && id <= bus.allowedIdMax;
}

static int circularDistance(int a, int b) {
  int distance = abs(a - b) % 4096;
  return min(distance, 4096 - distance);
}

static bool pingOnce(ServoBus &bus, int id) {
  return bus.driver->Ping(static_cast<uint8_t>(id)) == id;
}

static bool pingStable(ServoBus &bus, int id) {
  if (!pingOnce(bus, id)) {
    return false;
  }
  delay(3);
  return pingOnce(bus, id);
}

static bool pingWithRetries(ServoBus &bus, int id) {
  for (int attempt = 0; attempt < 3; ++attempt) {
    if (pingOnce(bus, id)) {
      return true;
    }
    delay(10);
  }
  return false;
}

static bool writeAcknowledgedWithoutError(ServoBus &bus, int result) {
  return result == 1 && bus.driver->Error == 0;
}

static void setupBus(ServoBus &bus) {
  bus.serial->begin(SERVO_BAUD, SERIAL_8N1, bus.rxPin, bus.txPin);
  bus.driver->pSerial = bus.serial;
  bus.driver->IOTimeOut = SERVO_IO_TIMEOUT_MS;
  delay(50);
}

static void printHelp() {
  Serial.println();
  Serial.println("Commands:");
  Serial.println("  scan        Scan IDs 0..20, disable torque, then watch for movement");
  Serial.println("  scan full   Scan IDs 0..253 (slower)");
  Serial.println("  list        Show the currently detected servo addresses");
  Serial.println("  watch       Reset position baselines and resume movement detection");
  Serial.println("  cancel      Cancel the selected servo or pending ID change");
  Serial.println("  isolated    Continue only after every other servo on that side is disconnected");
  Serial.println("  help        Show these instructions");
  Serial.println();
  Serial.println("Pairing flow:");
  Serial.println("  1. Move ONE joint by hand and hold it there.");
  Serial.println("  2. When it is detected, type its intended ID and press Enter.");
  Serial.println("  3. Isolate that servo when prompted; the tool verifies one address.");
  Serial.println("  4. Check the old/new IDs, then type yes within 60 seconds.");
  Serial.println();
  Serial.println("Expected final mapping: RIGHT IDs 1..4, LEFT IDs 5..8.");
  Serial.println("No position commands are sent by this sketch.");
  Serial.println();
}

static void printSafetyBanner() {
  Serial.println();
  Serial.println("Quadi STS3215 ID pairing tool - FIRST DRAFT");
  Serial.println("-------------------------------------------");
  Serial.println("Support the robot so every leg can move freely.");
  Serial.println("Both Waveshare adapters: UART jumper must be at A.");
  Serial.println("Use a servo-matched 12 V supply and share ground with the ESP32.");
  Serial.println();
  Serial.println("IMPORTANT: servos sharing one ID on the same bus cannot be");
  Serial.println("reliably distinguished. This tool will not write an ID until you");
  Serial.println("disconnect every other servo from the selected side and it verifies");
  Serial.println("that exactly one address responds on that bus.");
}

static void printTrackedServos() {
  Serial.println();
  Serial.println("SIDE\tID\tPOSITION\tTORQUE");
  if (trackedCount == 0) {
    Serial.println("(none detected)");
    return;
  }

  for (size_t i = 0; i < trackedCount; ++i) {
    const TrackedServo &servo = tracked[i];
    Serial.print(servo.bus->name);
    Serial.print('\t');
    Serial.print(servo.id);
    Serial.print('\t');
    if (servo.positionReadable) {
      Serial.print(servo.lastPosition);
    } else {
      Serial.print("read failed");
    }
    Serial.println(servo.torqueDisabled ? "\toff acknowledged" : "\tBLOCKED");
  }
  Serial.println();
}

static void resetSelection() {
  selectedServo = nullptr;
  requestedNewId = -1;
  isolationVerified = false;
  isolationVerifiedAtMs = 0;
  state = PairingState::WATCHING;
}

static void resetWatchBaselines() {
  resetSelection();
  pollIndex = 0;

  size_t readableCount = 0;
  for (size_t i = 0; i < trackedCount; ++i) {
    TrackedServo &servo = tracked[i];
    if (!servo.torqueDisabled) {
      continue;
    }
    int position = servo.bus->driver->ReadPos(servo.id);
    servo.positionReadable = position >= 0;
    servo.baselinePosition = position;
    servo.lastPosition = position;
    servo.movementHits = 0;
    if (servo.positionReadable) {
      ++readableCount;
    }
  }

  if (readableCount == 0) {
    Serial.println("No readable servo positions. Check power, UART wiring, and IDs.");
    return;
  }

  Serial.print("Watching ");
  Serial.print(readableCount);
  Serial.println(" servo address(es). Move ONE joint by hand and hold it.");
}

static void addTrackedServo(ServoBus &bus, int id, bool torqueDisabled) {
  if (trackedCount >= MAX_TRACKED_SERVOS) {
    return;
  }

  TrackedServo &servo = tracked[trackedCount++];
  servo.bus = &bus;
  servo.id = static_cast<uint8_t>(id);
  servo.baselinePosition = -1;
  servo.lastPosition = -1;
  servo.movementHits = 0;
  servo.positionReadable = false;
  servo.torqueDisabled = torqueDisabled;
}

static void scanBus(ServoBus &bus, uint8_t maxId) {
  Serial.print("Scanning ");
  Serial.print(bus.name);
  Serial.print(" bus, IDs 0..");
  Serial.print(maxId);
  Serial.println(" ...");

  size_t beforeCount = trackedCount;
  for (int id = MIN_SERVO_ID; id <= maxId; ++id) {
    if (!pingStable(bus, id)) {
      continue;
    }

    Serial.print("  Found ");
    Serial.print(bus.name);
    Serial.print(" ID ");
    Serial.println(id);

    int torqueResult = bus.driver->EnableTorque(static_cast<uint8_t>(id), 0);
    bool torqueDisabled = writeAcknowledgedWithoutError(bus, torqueResult);
    if (!torqueDisabled) {
      Serial.print("    BLOCKED: torque-off was not safely acknowledged (status ");
      Serial.print(bus.driver->Error);
      Serial.println("). This address will not be watched or paired.");
      continue;
    }

    addTrackedServo(bus, id, true);
  }

  Serial.print("  ");
  Serial.print(trackedCount - beforeCount);
  Serial.println(" address(es) found.");
}

static void scanAllBuses(uint8_t maxId) {
  resetSelection();
  trackedCount = 0;
  lastScanMaxId = maxId;

  Serial.println();
  for (size_t i = 0; i < BUS_COUNT; ++i) {
    scanBus(*buses[i], maxId);
  }

  if (trackedCount >= MAX_TRACKED_SERVOS) {
    Serial.println("Warning: tracking list is full; unexpected extra IDs may exist.");
  }

  printTrackedServos();
  if (trackedCount == 0 && maxId < MAX_SERVO_ID) {
    Serial.println("Nothing found in the quick range. Try: scan full");
    return;
  }

  if (trackedCount != 8) {
    Serial.print("Warning: expected 8 physical servos, but detected ");
    Serial.print(trackedCount);
    Serial.println(" unique bus/ID addresses.");
    Serial.println("Duplicate IDs on one side may appear as one address or fail to reply.");
  }

  resetWatchBaselines();
}

static void selectMovedServo(TrackedServo &servo, int position) {
  if (!servo.torqueDisabled) {
    return;
  }
  selectedServo = &servo;
  state = PairingState::AWAITING_TARGET_ID;

  Serial.println();
  Serial.println("Movement detected:");
  Serial.print("  Side: ");
  Serial.println(servo.bus->name);
  Serial.print("  Current ID: ");
  Serial.println(servo.id);
  Serial.print("  Start -> current: ");
  Serial.print(servo.baselinePosition);
  Serial.print(" -> ");
  Serial.println(position);
  Serial.print("Enter intended ID (");
  Serial.print(servo.bus->allowedIdMin);
  Serial.print("..");
  Serial.print(servo.bus->allowedIdMax);
  Serial.println(") or type cancel:");
}

static void pollForMovement() {
  if (state != PairingState::WATCHING || trackedCount == 0) {
    return;
  }
  if (millis() - lastPollMs < POLL_INTERVAL_MS) {
    return;
  }
  lastPollMs = millis();

  TrackedServo &servo = tracked[pollIndex];
  pollIndex = (pollIndex + 1) % trackedCount;

  int position = servo.bus->driver->ReadPos(servo.id);
  if (position < 0) {
    servo.positionReadable = false;
    servo.movementHits = 0;
    if (millis() - lastReadFailureReportMs >= READ_FAILURE_REPORT_MS) {
      Serial.println("A position read failed; watching continues. Type list for details.");
      lastReadFailureReportMs = millis();
    }
    return;
  }

  servo.positionReadable = true;
  servo.lastPosition = position;
  if (servo.baselinePosition < 0) {
    servo.baselinePosition = position;
    return;
  }

  int movement = circularDistance(servo.baselinePosition, position);
  if (movement >= MOVE_THRESHOLD_TICKS) {
    ++servo.movementHits;
    if (servo.movementHits >= MOVE_CONFIRM_READS) {
      selectMovedServo(servo, position);
    }
  } else {
    servo.movementHits = 0;
  }
}

static void requestIdChange(int newId) {
  if (!selectedServo) {
    resetWatchBaselines();
    return;
  }
  if (!isValidServoId(newId)) {
    Serial.println("Invalid ID. Servo IDs must be 0..253.");
    return;
  }
  if (!isAllowedTargetForBus(*selectedServo->bus, newId)) {
    Serial.print("That ID is on the wrong side. ");
    Serial.print(selectedServo->bus->name);
    Serial.print(" must use IDs ");
    Serial.print(selectedServo->bus->allowedIdMin);
    Serial.print("..");
    Serial.println(selectedServo->bus->allowedIdMax);
    return;
  }
  if (newId == selectedServo->id) {
    Serial.println("This servo already has that ID. Resuming watch mode.");
    resetWatchBaselines();
    return;
  }
  if (pingWithRetries(*selectedServo->bus, newId)) {
    Serial.println("REFUSED: the target ID already responds on this same bus.");
    Serial.println("Choose a free target ID. No EEPROM write was attempted.");
    return;
  }

  requestedNewId = newId;
  state = PairingState::AWAITING_ISOLATION;
  Serial.println();
  Serial.println("ID choice recorded, but EEPROM writing is still LOCKED:");
  Serial.print("  Side: ");
  Serial.println(selectedServo->bus->name);
  Serial.print("  Current ID: ");
  Serial.println(selectedServo->id);
  Serial.print("  New ID: ");
  Serial.println(requestedNewId);
  Serial.println();
  Serial.println("Required isolation step:");
  Serial.println("  1. Turn OFF the 12 V servo supply.");
  Serial.println("  2. Disconnect every other servo from this selected side/bus.");
  Serial.println("  3. Leave only the selected physical servo connected.");
  Serial.println("  4. Turn the 12 V servo supply back ON.");
  Serial.println("  5. Type isolated (or cancel). A full bus scan will verify one address.");
}

static void verifySelectedServoIsIsolated() {
  if (!selectedServo || requestedNewId < 0) {
    Serial.println("No selected servo is waiting for isolation.");
    resetWatchBaselines();
    return;
  }

  ServoBus &bus = *selectedServo->bus;
  int respondingCount = 0;
  int respondingId = -1;

  Serial.print("Full isolation scan on ");
  Serial.print(bus.name);
  Serial.println(" bus (IDs 0..253)...");

  for (int id = MIN_SERVO_ID; id <= MAX_SERVO_ID; ++id) {
    if (pingStable(bus, id)) {
      ++respondingCount;
      respondingId = id;
      Serial.print("  Responding ID: ");
      Serial.println(id);
    }
  }

  if (respondingCount != 1 || respondingId != selectedServo->id) {
    Serial.println("ISOLATION NOT VERIFIED. No write is allowed.");
    Serial.print("Expected only current ID ");
    Serial.print(selectedServo->id);
    Serial.print(", but found ");
    Serial.print(respondingCount);
    Serial.println(" stable address(es).");
    Serial.println("Power off, correct the isolation, power on, then type isolated again.");
    return;
  }

  int torqueResult = bus.driver->EnableTorque(selectedServo->id, 0);
  if (!writeAcknowledgedWithoutError(bus, torqueResult)) {
    selectedServo->torqueDisabled = false;
    Serial.println("ISOLATION FOUND, BUT TORQUE-OFF FAILED. No write is allowed.");
    return;
  }

  selectedServo->torqueDisabled = true;
  isolationVerified = true;
  isolationVerifiedAtMs = millis();
  state = PairingState::AWAITING_CONFIRMATION;

  Serial.println("ISOLATION VERIFIED: exactly one address responds and torque-off was acknowledged.");
  Serial.print("Final change: ");
  Serial.print(bus.name);
  Serial.print(" ID ");
  Serial.print(selectedServo->id);
  Serial.print(" -> ");
  Serial.println(requestedNewId);
  Serial.println("Type yes within 60 seconds to write once, or cancel.");
}

static void performConfirmedIdChange() {
  if (!selectedServo || requestedNewId < 0) {
    Serial.println("No complete ID change is pending.");
    resetWatchBaselines();
    return;
  }

  ServoBus &bus = *selectedServo->bus;
  const uint8_t oldId = selectedServo->id;
  const uint8_t newId = static_cast<uint8_t>(requestedNewId);

  if (!isolationVerified || millis() - isolationVerifiedAtMs > ISOLATION_CONFIRMATION_WINDOW_MS) {
    isolationVerified = false;
    state = PairingState::AWAITING_ISOLATION;
    Serial.println("STOPPED: isolation confirmation is missing or expired.");
    Serial.println("Keep one servo connected and type isolated again.");
    return;
  }

  int torqueResult = bus.driver->EnableTorque(oldId, 0);
  if (!writeAcknowledgedWithoutError(bus, torqueResult)) {
    Serial.println("STOPPED: final torque-off check failed. No EEPROM write was attempted.");
    state = PairingState::AWAITING_ISOLATION;
    isolationVerified = false;
    return;
  }

  if (!pingWithRetries(bus, oldId)) {
    Serial.println("STOPPED: the selected current ID no longer responds.");
    Serial.println("No EEPROM write was attempted. Rescan before continuing.");
    resetSelection();
    return;
  }
  if (pingWithRetries(bus, newId)) {
    Serial.println("STOPPED: the target ID began responding before the write.");
    Serial.println("No EEPROM write was attempted. Rescan before continuing.");
    resetSelection();
    return;
  }

  Serial.println("Writing ID once...");
  int unlockResult = bus.driver->unLockEprom(oldId);
  if (!writeAcknowledgedWithoutError(bus, unlockResult)) {
    Serial.println("STOPPED: EEPROM unlock was not safely acknowledged.");
    Serial.println("No ID write was sent. Check for duplicate IDs or flaky wiring.");
    resetSelection();
    return;
  }

  int writeResult = bus.driver->writeByte(oldId, SMS_STS_ID, newId);
  delay(POST_WRITE_DELAY_MS);

  // The write acknowledgement can be missed while the servo changes address,
  // so the new-address ping below is the deciding verification.
  if (!writeAcknowledgedWithoutError(bus, writeResult)) {
    Serial.println("Note: clean ID-write acknowledgement was not received; verifying addresses.");
  }

  bool newIdResponds = pingWithRetries(bus, newId);
  bool oldIdResponds = pingWithRetries(bus, oldId);

  if (newIdResponds && oldIdResponds) {
    int newLockResult = bus.driver->LockEprom(newId);
    bool newLockConfirmed = writeAcknowledgedWithoutError(bus, newLockResult);
    int oldLockResult = bus.driver->LockEprom(oldId);
    bool oldLockConfirmed = writeAcknowledgedWithoutError(bus, oldLockResult);
    Serial.println("STOPPED: both old and new IDs respond after the write.");
    Serial.println("Isolation was not valid. Keep the bus isolated and do not retry blindly.");
    Serial.print("Emergency lock status - old ID: ");
    Serial.print(oldLockConfirmed ? "confirmed" : "UNKNOWN");
    Serial.print(", new ID: ");
    Serial.println(newLockConfirmed ? "confirmed" : "UNKNOWN");
    trackedCount = 0;
    resetSelection();
    return;
  }

  if (!newIdResponds) {
    Serial.println("ID CHANGE NOT CONFIRMED.");
    if (oldIdResponds) {
      int recoveryLock = bus.driver->LockEprom(oldId);
      if (writeAcknowledgedWithoutError(bus, recoveryLock)) {
        Serial.println("The old ID still responds and its EEPROM was re-locked.");
      } else {
        Serial.println("The old ID responds, but EEPROM re-lock was NOT confirmed.");
      }
    } else {
      Serial.println("Neither address responds; EEPROM lock state is unknown.");
    }
    Serial.println("Keep this servo isolated, power-cycle it, then run scan full.");
    trackedCount = 0;
    resetSelection();
    return;
  }

  int lockResult = bus.driver->LockEprom(newId);
  delay(POST_WRITE_DELAY_MS);
  if (!writeAcknowledgedWithoutError(bus, lockResult)) {
    Serial.println("ID CHANGED, BUT EEPROM RE-LOCK WAS NOT CONFIRMED.");
    Serial.println("Keep this servo isolated. Power-cycle it, then ping the new ID before continuing.");
    trackedCount = 0;
    resetSelection();
    return;
  }

  int finalTorqueResult = bus.driver->EnableTorque(newId, 0);
  if (!writeAcknowledgedWithoutError(bus, finalTorqueResult)) {
    Serial.println("ID and EEPROM lock confirmed, but final torque-off was not confirmed.");
    Serial.println("Power off the 12 V supply before reconnecting the other servos.");
  }

  Serial.print("CONFIRMED AND LOCKED: ");
  Serial.print(bus.name);
  Serial.print(" servo now responds as ID ");
  Serial.println(newId);
  Serial.println("Turn OFF 12 V, reconnect the other servos, turn power on, then type scan.");
  trackedCount = 0;
  resetSelection();
}

static void handleLine(String line) {
  line.trim();
  line.toLowerCase();
  if (line.length() == 0) {
    return;
  }

  if (line == "help" || line == "?") {
    printHelp();
    return;
  }
  if (line == "list") {
    printTrackedServos();
    return;
  }
  if (line == "scan") {
    scanAllBuses(DEFAULT_SCAN_MAX_ID);
    return;
  }
  if (line == "scan full") {
    scanAllBuses(MAX_SERVO_ID);
    return;
  }
  if (line == "watch") {
    resetWatchBaselines();
    return;
  }
  if (line == "cancel") {
    Serial.println("Pending selection cancelled.");
    resetWatchBaselines();
    return;
  }

  if (state == PairingState::AWAITING_TARGET_ID) {
    char *end = nullptr;
    long value = strtol(line.c_str(), &end, 10);
    if (end == line.c_str() || *end != '\0') {
      Serial.println("Enter only the intended numeric ID, or type cancel.");
      return;
    }
    requestIdChange(static_cast<int>(value));
    return;
  }

  if (state == PairingState::AWAITING_ISOLATION) {
    if (line == "isolated") {
      verifySelectedServoIsIsolated();
    } else {
      Serial.println("Type isolated after the physical isolation steps, or cancel.");
    }
    return;
  }

  if (state == PairingState::AWAITING_CONFIRMATION) {
    if (line == "yes") {
      performConfirmedIdChange();
    } else {
      Serial.println("Type yes to write, or cancel to stop.");
    }
    return;
  }

  Serial.println("Unknown command. Type help.");
}

void setup() {
  Serial.begin(CONSOLE_BAUD);
  Serial.setTimeout(50);
  delay(1500);

  setupBus(rightBus);
  setupBus(leftBus);

  printSafetyBanner();
  printHelp();
  Serial.println("Starting quick scan automatically...");
  scanAllBuses(DEFAULT_SCAN_MAX_ID);
}

void loop() {
  if (Serial.available() > 0) {
    String line = Serial.readStringUntil('\n');
    handleLine(line);
  }
  pollForMovement();
}

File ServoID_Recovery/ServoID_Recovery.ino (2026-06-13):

#include <SCServo.h>

// ESP32-S3 wiring:
// Bus 1: RX 18, TX 17
// Bus 2: RX 16, TX 15
// Change these if your board uses different free GPIOs.
constexpr uint8_t BUS1_RX_PIN = 18;
constexpr uint8_t BUS1_TX_PIN = 17;
constexpr uint8_t BUS2_RX_PIN = 16;
constexpr uint8_t BUS2_TX_PIN = 15;

constexpr uint32_t CONSOLE_BAUD = 115200;
constexpr uint32_t SERVO_BAUD = 1000000;
constexpr unsigned long SERVO_IO_TIMEOUT_MS = 60;
constexpr uint8_t MIN_SERVO_ID = 0;
constexpr uint8_t MAX_SERVO_ID = 253;
constexpr uint8_t BROADCAST_ID = 0xFE;

constexpr int PING_RETRIES = 3;
constexpr uint16_t PING_RETRY_DELAY_MS = 35;
constexpr uint16_t POST_WRITE_DELAY_MS = 100;
constexpr int PING_CONFIRM_HITS = 2;

struct ServoBus {
  const char* label;
  HardwareSerial* serial;
  SMS_STS* driver;
  uint8_t rxPin;
  uint8_t txPin;
};

SMS_STS bus1Driver;
SMS_STS bus2Driver;

ServoBus buses[] = {
  {"bus 1", &Serial1, &bus1Driver, BUS1_RX_PIN, BUS1_TX_PIN},
  {"bus 2", &Serial2, &bus2Driver, BUS2_RX_PIN, BUS2_TX_PIN},
};

constexpr size_t BUS_COUNT = sizeof(buses) / sizeof(buses[0]);

ServoBus* getBus(int busNumber) {
  if (busNumber < 1 || busNumber > static_cast<int>(BUS_COUNT)) {
    return nullptr;
  }
  return &buses[busNumber - 1];
}

bool isValidServoId(int id) {
  return id >= MIN_SERVO_ID && id <= MAX_SERVO_ID;
}

void setupBus(ServoBus& bus) {
  bus.serial->begin(SERVO_BAUD, SERIAL_8N1, bus.rxPin, bus.txPin);
  bus.driver->pSerial = bus.serial;
  bus.driver->IOTimeOut = SERVO_IO_TIMEOUT_MS;
  delay(50);
}

bool pingOnce(ServoBus& bus, int id) {
  return bus.driver->Ping(static_cast<uint8_t>(id)) != -1;
}

bool pingConfirmed(ServoBus& bus, int id) {
  int hits = 0;
  for (int attempt = 0; attempt < PING_RETRIES; ++attempt) {
    if (pingOnce(bus, id)) {
      ++hits;
    }
    delay(PING_RETRY_DELAY_MS);
  }
  return hits >= PING_CONFIRM_HITS;
}

bool pingWithRetries(ServoBus& bus, int id) {
  for (int attempt = 0; attempt < PING_RETRIES; ++attempt) {
    if (pingOnce(bus, id)) {
      return true;
    }
    delay(PING_RETRY_DELAY_MS);
  }
  return false;
}

void printBanner() {
  Serial.println();
  Serial.println("Quady servo ID recovery");
  Serial.println("------------------------");
  Serial.println("Two independent servo buses are available.");
  Serial.println("Leave both controllers plugged in, then use the commands below.");
  Serial.println();
  Serial.println("Important:");
  Serial.println("- If two servos on the same bus share the same ID, the bus cannot tell them apart.");
  Serial.println("- In that case, software alone may not be enough to repair both.");
  Serial.println();
}

void printHelp() {
  Serial.println("Commands:");
  Serial.println("  help");
  Serial.println("  scan <bus|all> [startId endId]");
  Serial.println("  scanraw <bus|all> [startId endId]");
  Serial.println("    example: scan 1");
  Serial.println("    example: scan all 0 253");
  Serial.println("  ping <bus> <id>");
  Serial.println("    example: ping 2 7");
  Serial.println("  set <bus> <currentId> <newId>");
  Serial.println("    example: set 1 12 3");
  Serial.println("  wizard <bus>");
  Serial.println("    example: wizard 1");
  Serial.println();
}

void printPrompt() {
  Serial.print("quady-id> ");
}

int normalizeRangeStart(int value) {
  if (value < MIN_SERVO_ID) return MIN_SERVO_ID;
  if (value > MAX_SERVO_ID) return MAX_SERVO_ID;
  return value;
}

int normalizeRangeEnd(int value) {
  if (value < MIN_SERVO_ID) return MIN_SERVO_ID;
  if (value > MAX_SERVO_ID) return MAX_SERVO_ID;
  return value;
}

void printScanResult(ServoBus& bus, int id) {
  Serial.print("  ");
  Serial.print(bus.label);
  Serial.print(" ID ");
  Serial.print(id);
  Serial.println(" FOUND");
}

int scanRange(ServoBus& bus, int startId, int endId, bool stableMode) {
  if (startId > endId) {
    int tmp = startId;
    startId = endId;
    endId = tmp;
  }

  startId = normalizeRangeStart(startId);
  endId = normalizeRangeEnd(endId);

  Serial.print("Scanning ");
  Serial.print(bus.label);
  Serial.print(" from ");
  Serial.print(startId);
  Serial.print(" to ");
  Serial.println(endId);

  int foundCount = 0;
  for (int id = startId; id <= endId; ++id) {
    bool found = stableMode ? pingConfirmed(bus, id) : pingWithRetries(bus, id);
    if (found) {
      printScanResult(bus, id);
      ++foundCount;
    }
  }

  Serial.print("Scan complete on ");
  Serial.print(bus.label);
  Serial.print(": ");
  Serial.print(foundCount);
  Serial.println(" servo(s) found.");
  if (foundCount == 0) {
    Serial.println("Check power, wiring, and bus selection.");
  }
  Serial.println();
  return foundCount;
}

void scanAll(int startId, int endId) {
  for (size_t i = 0; i < BUS_COUNT; ++i) {
    scanRange(buses[i], startId, endId, true);
  }
}

void scanAllLoose(int startId, int endId) {
  for (size_t i = 0; i < BUS_COUNT; ++i) {
    scanRange(buses[i], startId, endId, false);
  }
}

bool changeServoId(ServoBus& bus, int currentId, int newId) {
  if (!isValidServoId(currentId) || !isValidServoId(newId)) {
    Serial.println("ID out of range. Use 0..253.");
    return false;
  }

  if (currentId == newId) {
    Serial.println("Current ID and new ID are the same.");
    return false;
  }

  if (newId == BROADCAST_ID) {
    Serial.println("New ID cannot be 254 (broadcast).");
    return false;
  }

  Serial.print("Bus ");
  Serial.print(bus.label);
  Serial.print(": changing ");
  Serial.print(currentId);
  Serial.print(" -> ");
  Serial.println(newId);

  if (!pingWithRetries(bus, currentId)) {
    Serial.println("Current ID not found on this bus.");
    return false;
  }

  if (pingWithRetries(bus, newId)) {
    Serial.println("Target ID already responds on this bus.");
    Serial.println("Pick a different new ID first.");
    return false;
  }

  int unlockResult = bus.driver->unLockEprom(static_cast<uint8_t>(currentId));
  if (unlockResult == 0) {
    Serial.println("Warning: EEPROM unlock did not ack.");
  }
  delay(20);

  int writeResult = bus.driver->writeByte(static_cast<uint8_t>(currentId), SMS_STS_ID, static_cast<uint8_t>(newId));
  if (writeResult == 0) {
    Serial.println("Warning: ID write did not ack.");
  }
  delay(POST_WRITE_DELAY_MS);

  int lockResult = bus.driver->LockEprom(static_cast<uint8_t>(newId));
  if (lockResult == 0) {
    Serial.println("Warning: EEPROM lock did not ack.");
  }
  delay(POST_WRITE_DELAY_MS);

  if (pingWithRetries(bus, newId)) {
    Serial.print("Verified new ID on ");
    Serial.print(bus.label);
    Serial.print(": ");
    Serial.println(newId);
    Serial.println();
    return true;
  }

  Serial.println("Could not confirm the new ID.");
  Serial.println("Rescan this bus to verify what responded.");
  Serial.println();
  return false;
}
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

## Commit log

2026-06-04 Servo testing
2026-06-05 Made some initial cad designs
    [ST3215.step, Test Measurments Part.stl]
2026-06-07 Day 2 of designing done
    [Body.stl, Lower Leg.stl, Quady Assembly V1.f3z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]
2026-06-13 I upgraded my ServoTester to be more useful script
    [Quady Assembly.f3z, Quady Assembly.step, ServoClip.stl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]
2026-07-02 Added step files for the current design of the parts
    [Body.step, Lower Leg.step, Upper Leg.step]
2026-07-02 assembly instructions
2026-07-02 Clarify assembly instructions reference in README
    Updated the assembly instructions reference for clarity.
2026-09-01 finial commit
    [Quady Assembly.f3z, Quady Assembly.step, Quady_Board_Parameters.csv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]
2026-09-01 commit bom
    [BOM.csv]
